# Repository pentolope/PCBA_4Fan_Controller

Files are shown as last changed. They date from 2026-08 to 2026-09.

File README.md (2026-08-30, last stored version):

# Four-Fan PWM/Tach Controller

Board that powers and controls four standard 4-wire 12 V PC fans, with a microcontroller giving independent PWM and tach per fan from a single 12 V input.

This repository holds the design problem for a four-channel PC fan controller. The brief fixes the function and almost nothing else: four standard 4-wire 12 V PC fans are powered and controlled from the board, a microcontroller generates independent PWM and reads independent tach signals, the board accepts a single 12 V input and derives its logic power locally, protection is required, and a simple host interface is to be provided. It also asks that the board be kept compact and serviceable, without stating any dimension, outline, or mounting scheme.

At brief detail 1/5, everything below that statement of function is left to the design agent: microcontroller family, logic rail voltage and regulator topology, host interface protocol and physical connection, how the fans and the 12 V input attach to the board, per-fan current budget, what "sensible protection" concretely covers, board outline, and stackup. Those choices belong in the design record as decisions with rationale, not as requirements attributed to the brief.

> **This board has not been designed.** There is no schematic, no layout and no
> part selection here — only the brief, a reading of the brief, and the
> scaffolding a design run needs. That is the intended state of this repository,
> not a gap in it.

## What the brief fixes, and what it leaves open

The brief pins down 11 requirements and deliberately leaves
17 decisions to whoever designs the board. The `Source` column says
which is which: `brief` is quoted from [BRIEF.md](BRIEF.md), `metadata` comes
from the benchmark catalogue, and `open` means the brief does not fix it.

| Aspect | Value | Source |
|---|---|---|
| Fan channels | Four standard 4-wire 12 V PC fans, powered and controlled by the board | brief |
| Fan control signals | Independent PWM per fan (four independent PWM outputs) | brief |
| Fan feedback signals | Independent tach read per fan (four independent tach inputs) | brief |
| Control element | A microcontroller performs PWM generation and tach reading; no family, package, or vendor named | brief |
| Power input | A single 12 V input, accepted by the board; the brief fixes one 12 V input and says nothing about whether anything else (for example the host link) also supplies power | brief |
| Logic power | Derived locally on the board rather than supplied externally; rail voltage and conversion method not stated | brief |
| Protection | Protection is required; the brief says only "sensible" and names no fault modes or devices | brief |
| Host interface | A simple host interface is to be provided; protocol, physical layer, and physical connection not specified | brief |
| Mechanical intent | Compact and serviceable; no dimensions, outline, mounting pattern, or enclosure stated | brief |
| Likely layer count | 2 | metadata |
| Category / difficulty / brief detail | mixed-power-digital; difficulty 2/5; detail 1/5 | metadata |
| Primary stressors | PWM/tach routing, 12V distribution, connector density, power thermal | metadata |
| Microcontroller, regulator, and connector selection | Not fixed by the brief — design agent's choice, to be justified in the design record | open |
| Board outline, stackup, and 12 V current budget | Not fixed by the brief — design agent's choice; no size, copper weight, or per-fan current is stated | open |
| Whether any supply other than the 12 V input exists | Not fixed by the brief — one 12 V input is fixed and logic power must be derived locally, but the brief does not say whether the host connection or a programming/bring-up link may also carry power; the design agent decides and records this | open |

The full split, with the verbatim brief text substantiating every fixed
requirement, is in [board/requirements.md](board/requirements.md) and
machine-readably in [board/requirements.json](board/requirements.json).

**Missing details are design freedom, not permission to fabricate unstated user
requirements.** A choice the brief left open is recorded as a decision, with its
reasoning — never promoted into a requirement.

## Benchmark position

| | |
|---|---|
| Benchmark id | 4 of 32 |
| Category | mixed-power-digital |
| Difficulty | 2 / 5 |
| Brief detail | 1 / 5 |
| Likely layer count | 2 |
| Primary stressors | PWM/tach routing, 12V distribution, connector density, power thermal |

This is a mixed-power-digital board at difficulty 2/5 with a detail 1/5 brief — a modest circuit whose difficulty lies in the interface between a 12 V power path and low-voltage digital control on a likely 2-layer stackup. The named stressors are PWM/tach routing, 12V distribution, connector density, and power thermal: four fan connections plus the 12 V input and the host interface all have to land on a board the brief asks to keep "compact", whatever connector scheme is chosen, while eight switching and feedback signals route alongside the fan current path. Because the brief specifies function but no parts, voltages, currents, or geometry, it primarily tests whether an agent can carry a thin brief forward with documented engineering decisions instead of back-filling invented user requirements.

This repository is one of thirty-two. The suite, the protocol and the results
live in [PCBA_AutoDesignAndTest_Bench](https://github.com/pentolope/PCBA_AutoDesignAndTest_Bench).

## Repository layout

| Path | Contents |
|---|---|
| `BRIEF.md` | the supplied brief — authoritative, preserved byte for byte, never edited |
| `board/requirements.md` | what the brief fixes, what it leaves open, and where decisions get recorded |
| `board/requirements.json` | the same split, machine-readable, each fixed requirement bound to brief text |
| `board/manifest.template.json` | the toolkit's minimum manifest, pre-filled for this board |
| `board/toolchain.json` | where this board's build finds KiCad and the router |
| `benchmark/metadata.json` | the supplied catalogue entry — category, difficulty, detail, stressors |
| `docs/architecture.md` | the decisions this board must make, as questions, unanswered |
| `docs/sources.md` | the classes of evidence the design will have to cite |
| `docs/status.md` | what exists, what does not, and what is deliberately absent |
| `candidates/` | disposable search output, ignored by Git |
| `.claude/skills/` | the accountability-review skill [CLAUDE.md](CLAUDE.md) requires before a push |
| `tooling/PCBA_AutoDesignAndTest` | the shared verification/routing/release toolkit, as a pinned submodule |

## Getting the repository

The toolkit is a submodule and carries KiCad Routing Tools as a submodule of its
own, so clone recursively:

```bash
git clone --recursive https://github.com/pentolope/PCBA_4Fan_Controller.git
```

```bash
git submodule update --init --recursive
```

## Designing the board

Generic verification, routing and release logic is **not** written here. It is
consumed from `tooling/PCBA_AutoDesignAndTest`, which is board-agnostic by
construction and must stay that way; this repository owns the board and nothing
else. Start from
[the toolkit's onboarding guide](tooling/PCBA_AutoDesignAndTest/examples/onboarding.md),
and see [CLAUDE.md](CLAUDE.md) for the rules a design run works under.

```bash
python3 tooling/PCBA_AutoDesignAndTest/run.py preflight
```

## Brief integrity

`BRIEF.md` SHA-256 `531862b585105d510d5cae2a7e9f812644b966f14cebd01fc22d28720cdb2ca3`

Every quotation in `board/requirements.json` is bound to those exact bytes. If
the brief ever changes, the bindings are stale by construction — which is the
point of recording the digest.

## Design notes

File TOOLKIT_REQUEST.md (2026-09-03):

# Toolkit requests from board 04 (QuadFanController)

What this board needed from `PCBA_AutoDesignAndTest` and did not get, what it
had to build for itself that every other board will have to build again, and
what it still cannot establish about its own reliability.

Written after taking the board to a release-ready state: 22 applicable gates
pass, 177 requirement claims stand at 176 PASS and 1 UNKNOWN, `release-check`
reports RELEASE READY. Everything below is therefore a request about the *next*
board as much as this one.

**Every request here is board-agnostic by construction.** Board 04 appears only
as evidence — what it measured, what it cost, what it could not answer. Nothing
asks the toolkit to learn anything about fans, four channels, or this netlist.
Where a board must supply something specific, the request says so and names the
declaration, not the value.

I surveyed `pcbqa/` before writing this. Section E lists what already exists and
must not be rebuilt; several things I expected to ask for are already there.

---

## A. Blockers hit while building this board

These cost real time on board 04 and will cost it again unchanged. They are
ordered by how much they cost.

### A1. The router grades the board against a floor it lowers itself

**Problem.** `KiCadRoutingTools` carries its own fab-capability floor —
`py_router/fab_tiers.py` gives a two-layer `standard` board 0.127 mm clearance
and 0.127 mm track width — and individual routing steps escalate *below* the
nominal `--clearance` to fit tight geometry. `py_router/clearance_ledger.py`
records the tightest value any step used, and its own docstring states where
that value goes: into `fix_project_for_output`, which rewrites the sibling
`.kicad_pro` DRC floor so the board is subsequently graded at the relaxed
value.

This board declares 0.15 mm and is graded at 0.15 mm. Every clearance violation
I chased for several routing cycles — 37 in one candidate, 42 in another, all
between 0.116 mm and 0.144 mm — was copper that is legal at 0.127 and illegal
at 0.15. Nothing in the flow said so. The router reported success; the summary
field `min_clearance_used: 0.127` was the only trace, and it is not surfaced by
any gate.

Passing `--fab-overrides` with the board's declared constraints fixed it
completely: the accepted candidate then reported `min_clearance_used: 0.3`, the
full nominal, and the violations disappeared at the source rather than being
patched afterwards.

**Request.** The toolkit's routing entry point should own this:

1. derive the router's fab-floor override file from the board's declared
   constraints (the same values `DRC.CONSTRAINT_FLOOR` already checks) and pass
   it on every invocation, so the router cannot emit copper the checker will
   reject;
2. read back the router's reported minimum clearance and **refuse the
   candidate** when it is below the board's declared clearance, naming both
   numbers;
3. detect that a router invocation rewrote the project's DRC floor and treat it
   as a finding, not as housekeeping. A tool lowering the threshold a later gate
   reads is check-weakening arriving through the back door, and the board author
   currently has to know it happens to defend against it.

**Done when** a board whose declared clearance is tighter than the router's tier
floor either routes at its declared clearance or fails with a message naming the
two floors — and no board-owned code has to know that `fab_tiers.py` exists.

### A2. The router is not deterministic, and the candidate search is board-owned

**Problem.** The same placed board, the same ordering, the same options,
re-run: 0 errors, then 44, then 64. Attempts 1 and 2 reproduced exactly while
attempt 3 did not, so this is not a seeded search the caller can pin.

That makes routing a search whose acceptance must be repeated, and every board
must therefore own: attempt loop, ordering list, per-attempt staging, the
acceptance predicate, retry-on-rejection, and the provenance record of what was
tried. `design/route.py` on this board is ~300 lines of exactly that, and
`routing_record.py` validates the record it produces but does not produce it.

**Request.** A toolkit-owned candidate search: the board declares the router
options, the orderings, the attempt budget and the acceptance predicate (as a
set of counters that must be zero — this board uses errors, warnings,
unconnected, schematic parity); the toolkit runs the attempts, stages each one,
applies the declared transforms, measures, promotes the first accepted candidate
into the authoritative board and emits the record `routing_record.validate`
already knows how to check. It should also report the accept rate across
attempts, because that number is the honest measure of how reproducible a
board's routing is.

**Done when** a board can obtain an accepted, recorded routing run without
owning a loop, and two runs of the same board report the same verdict even
though the router does not return the same copper.

### A3. Post-router geometry repair is board-owned and easy to get wrong

**Problem.** Router output is not directly acceptable. This board needed seven
transforms, all generic, none board-specific:

- snap a track end standing inside a same-net via's annulus onto its centre;
- pull a track end that stopped inside a same-net pad's outline onto the pad
  anchor (a 45° corner landing in the cut corner of a rounded rectangle reads as
  connected to KiCad's connectivity and as a bare end to everything else);
- drop tracks a snap collapsed to zero length;
- widen any track the router necked below the declared floor;
- restore the declared size on any via the router narrowed;
- absorb chamfer fragments a few tens of microns long into their single
  neighbour, away from pads and vias;
- prune dangling ends.

The last three are only safe under a connectivity-invariance guard: apply,
rebuild connectivity, and revert if the unconnected count rose. I wrote that
guard three times across two stages of this work.

**Request.** These transforms belong in the toolkit, each with the invariance
guard built in, each reporting what it changed so the routing record can carry
it. The board should declare which to apply and with what tolerances, not
implement them.

**Done when** a board gets router output into an acceptable state by declaring a
transform list, and the effects appear in the routing record without board-side
bookkeeping.

### A4. KiCad object identity has a trap that silently disables correct code

**Problem.** `str(track.m_Uuid)` returns a SWIG proxy repr — an address, reused
as objects are freed. On this board, **1190 tracks shared 3 distinct strings**.
Code comparing track identities that way is not merely wrong, it is wrong in the
direction that looks fine: my dangling-end prune skipped nothing, because every
track matched itself out of the neighbour scan and then held its own ends up.
The prune reported `dangling_tracks_removed: 0` for weeks of work while the
geometry gate kept reporting dangling ends, and the two facts never met.
`m_Uuid.AsString()` is the correct accessor.

**Request.** A `pcbqa` helper — `item_id(item)` — that returns the KIID string,
used by every toolkit path that compares board items, and one sentence in the
KiCad-interaction documentation stating the trap. This is three lines of code
that prevents a class of silent failure no test naturally catches, because the
broken version produces plausible output.

### A5. Saving a board rewrites the project document

**Problem.** `pcbnew.SaveBoard` rewrites the sibling `.kicad_pro` with KiCad's
own defaults, discarding the board's declared rule severities. On this board
that surfaced as `DRC.NO_SUPPRESSED_RULES` failing with five rules set to
"ignore" that the board never set to ignore. The fix — rewrite the project
document after every save — has to be remembered at every call site.

**Request.** A `pcbqa` save entry point that preserves the project document, and
which board-side layout code can use instead of `pcbnew.SaveBoard` directly.

### A6. Gate findings are not addressable

**Problem.** `ROUTE.GEOMETRY_HYGIENE` reports, for example,
`net=+3V3, layer=F.Cu, x_mm=71.8, y_mm=-42.9`. Those are KiCad-frame
coordinates with y negated, not board coordinates, and there is no item
identity. Locating each finding meant mapping the frame by hand and then
searching the board for copper near the point — several times per routing cycle,
and once with the wrong sign, which sent me looking at empty board area.

**Request.** Geometry findings should carry the board-frame coordinate *and* the
offending item's identity: net, layer, KIID, and where applicable the footprint
reference and pad number. `feedback.py` already establishes the principle — a
finding must name what failed, where, by how much, and which variables may move
— so this is asking the geometry gates to emit what that module already models.

**Done when** a finding can be resolved to the item it is about without a
coordinate-frame conversion in the reader's head.

### A7. Placement seeds need measured footprint geometry, not guesses

**Problem.** Seeding placement means knowing a footprint's courtyard extent and
where pad 1 sits after rotation. Both are empirical: rotation 90 puts pad 1
below the footprint centre and 270 above it; a vertical pin header places pad 1
at the origin and runs in −y. I discovered each by producing a board, running
DRC, reading the overlap, and adjusting — and eventually wrote a scratch script
to measure courtyard bounding boxes from the library so the constants could be
derived rather than guessed.

**Request.** A small geometry query on top of the footprint libraries:
courtyard extent, pad-1 position and pad centroid for a given footprint at a
given rotation. `geom.py` already reads pad outlines and mask openings from a
board; this is the same question asked of a library before a board exists.

### A8. `checks.<tool>.output` accepts a path that lands in the repository root

**Minor.** This board's manifest declared `"drc": {"output": "drc.json"}`; the
report landed at the repository root as an untracked file and nothing
complained. My fault, but the schema could refuse an output path that is not
inside a declared generated location.

---

## B. What the remaining stages need

Per `AUTONOMOUS_PCBA_AGENT.md`, this board has completed through §20 and §32.
§21–§26 are open. Some of what they need already exists; the gaps below are the
parts that do not.

### B1. A wired path from a board to the extraction modules that already exist

**Problem.** `extract.py`, `electrical_path.py`, `propagation.py`,
`coupling_geometry.py` and `stackup_physical.py` are present and do most of what
§21.1 asks. Board 04 uses none of them, and its `TIMING.*`, `STACK.PHYSICAL` and
`PROV.TIMING_MODELS` gates all report NOT_APPLICABLE because the manifest
declares no `timing` section. The capability exists; the route from a board to
it does not, and nothing tells a board author it is there.

**Request.** A documented opt-in: what a board declares to get Tier-1
extraction, what physical inputs it must supply as parameter records, and which
gates become applicable when it does. A worked minimal example in the toolkit's
own fixtures is worth more than prose.

**Done when** a board can obtain per-net conductor length, cross-section, DC
resistance, via inventory and reference-plane context as claims by declaring
inputs, without reading module source to discover the calling convention.

### B2. Pre-layout versus post-layout comparison (§22)

**Problem.** `simulation.required_stages` on this board is `["pre_layout"]`.
The scenario contract supports `model_instance`, and `extract.py` already offers
`interconnect_model_from_path` — a two-terminal model from a traced path — so
the primitives for substitution exist. What does not exist is the comparison the
doc actually asks for: *pre-layout model vs post-layout model*, stating which
quantity moved and by how much.

**Request.** A stage-comparison artifact and gate: given the same scenario run
in two stages, report per measurement the pre value, the post value, the change,
and whether the assertion's margin narrowed. A post-layout stage that merely
passes tells the reader nothing about what layout cost.

**Done when** a board can answer "did the routed copper change this margin, and
by how much" from an artifact rather than by diffing two reports by eye.

### B3. DC power integrity (§23) — absent

**Problem.** No module in `pcbqa` addresses IR drop, source-to-load DC
resistance over routed copper, current bottlenecks or plane spreading
resistance; a grep for the concepts returns nothing. Board 04 declares
`INPUT_PATH_BUDGET_OHM = 0.2` and `BOARD_COPPER_BUDGET_OHM = 0.03` as *budgets*
and has no way to measure what its routed rail and return actually are. It
carries 4 A through one input path and cannot state the drop.

`extract.py:path_resistance` gets close — DC resistance over an actual traversal
between two pads — but it refuses when the net carries filled zone copper, which
is precisely the case for a poured power rail and a ground return, so it does
not answer the power question.

**Request.** A DC distribution analysis: given a source pad, a set of load pads
and their currents, report the resistance and voltage drop along each path
**including plane and pour copper**, identify the narrowest point and the vias
carrying the most current, and emit claims with the model and its omissions
stated. Zone copper is the hard part and the reason this cannot be assembled
from what exists.

**Done when** a board that declares a rail's source, loads and currents receives
a measured drop it can compare against a declared budget, and a via or neck that
carries more current than the rest is named.

### B4. Thermal estimation (§24) — absent

**Problem.** No thermal capability exists. Two of this board's claims sit
exactly on the failure mode the agent doc names by hand — a junction temperature
from a generic package number whose boundary conditions do not match:

- `blocking_device_dissipation_within_its_rating` (Q1), omitting *"the package's
  power rating is quoted on the datasheet's own test board; the copper this
  board gives the drain is a layout quantity and is not yet measured"*;
- `regulator_junction_within_its_rating` (U2), omitting the same for its tab.

The copper now exists. The omissions can be closed, and cannot be closed by
anything in the toolkit.

**Request.** A copper-aware thermal estimate: pad and plane copper area attached
to a part, thermal via conductance, declared ambient and airflow as explicit
inputs, and a result **labelled an estimate** with its validity envelope stated.
It should refuse to emit a junction-temperature claim when the declared boundary
conditions fall outside the validity of the θJA it was given, rather than
quietly extrapolating — the doc asks for that refusal specifically.

**Done when** a dissipating part's claim can cite measured attached copper
instead of omitting it, and a board whose conditions do not match its
datasheet's test board is told so.

### B5. Design-for-assembly checks (§25) — absent

**Problem.** `gates/g_assembly.py` is BOM and CPL *parity* — it proves the
schematic, board and packaged files agree on what gets soldered. It is not DFA.
Nothing checks component height, insertion or mating access, side-of-board
population, paste segmentation on a thermal tab, hand-solder sets, moisture
sensitivity, or fiducials.

Board 04 is a case where access is a real constraint and is currently unchecked:
four fan headers and a screw terminal sit on the board edge, and nothing
verifies a plug can be inserted, or that a mating connector's body does not
collide with a neighbouring part.

**Request.** Assembly constraints as board-declared, toolkit-checked geometry:
height limits per region, keep-clear volumes for connector insertion and mating,
population side, and paste-mask rules. The connector contracts this board
already declares are the natural place to attach a mating envelope.

### B6. External and manual release dependencies (§25, §32)

**Problem.** Some release conditions cannot be established locally — the doc
names JLCPCB's assembly preview. Today they are either silently assumed or
recorded as prose that no gate reads.

**Request.** A manifest-declared external dependency with an acknowledgement
artifact: what must be checked outside the toolkit, by whom, and a recorded
result with a digest, so `release-check` blocks until an unacknowledged
dependency is either satisfied or explicitly declined. Recording it as an
open dependency is honest; assuming it silently is not.

### B7. Verification-method classification (§26)

**Problem.** Claims carry `evidence_class` (this board: 101
`datasheet-behavioral`, 66 `design-source`, 10 `assumed-behavioral`) and
`phenomenon` (all 177 `device_electrical`), but not the strongest verification
method available for the requirement. The doc's enumeration — STATIC, GEOMETRY,
ANALYTIC, CIRCUIT_SIM, DIGITAL_SIM, EXTRACTED, EM_SIM, THERMAL_SIM,
MANUFACTURING_CHECK, PHYSICAL_TEST, DOCUMENTATION — has no representation in
`claim.py`.

The consequence is that this board cannot say the true thing about several
requirements. Connector mating, TVS survival to a real ESD event, and the fan's
own rotor-lock behaviour are `PHYSICAL_TEST` and nothing else. Today the mating
requirement is the board's single UNKNOWN, which reads like an oversight rather
than like a correct statement that a bench test is required.

**Request.** A method field on claims, a gate that every significant requirement
names its strongest available method, and — the part that matters — a verdict
shape for "physical validation required" that is neither a FAIL nor an UNKNOWN
that looks like a gap. The doc says the agent should be rewarded for saying it;
right now there is nowhere to say it.

### B8. Board-contract export for firmware (§6.3)

**Problem.** This design determines firmware behaviour and records it only as
prose in comments: the PWM drivers are external open-drain N-FETs, so the
timer's channel polarity must be inverted; the 25 kHz target comes out as
ARR = 639 on a 16 MHz HSI; and the control gate sits at 2.664 V under the MCU's
internal pull-up before firmware runs, which constrains what the pin may be
configured to at boot. Firmware that gets any of these wrong runs the fans
backwards or full-speed. The doc's rule is not to maintain two independently
edited copies of the board contract, and today there is only prose to copy from.

**Request.** Generated machine-readable board contract: pin assignments,
voltage domains, clock sources, per-pin polarity and boot-state constraints,
derived from the netlist the board already declares. Format is the toolkit's
call; the requirement is that it is generated, not authored twice.

---

## C. Verifying this board's reliability

Three things I want and cannot get, all generic.

### C1. Flow repeatability

Given A2, "this board routes clean" is a statement about one run. The honest
claim is about the distribution: run generate → route → validate N times from
the same sources and report whether the verdict is stable and which gates ever
differ. That number belongs in the release evidence for any board whose routing
came from a non-deterministic search — which, today, is all of them.

### C2. Omission-closure report

Every claim states what it omits. Some omissions name quantities that were
unmeasurable at the stage the claim was written and are measurable now: on this
board, 8 of 177 claims omit a layout or thermal quantity that the routed board
now contains. I found that with an ad-hoc script to answer a question about what
work remained.

**Request.** A report listing every claim whose omissions name a quantity the
current stage can measure. It is the work list for post-layout verification,
it is derivable from the claim records the toolkit already owns, and it turns
"what is left to do" from a judgement call into a query.

### C3. Per-gate negative coverage

`tests/fixtures/negative/` holds one fixture, which drives 15 of the 36 gates to
FAIL. The other 21 have no fixture proving they fail when they should. A gate
that cannot be shown to bite is indistinguishable from a gate that always
passes, and the discipline this toolkit applies to boards — unknown is not pass
— applies to the checker too.

**Request.** Per-gate negative coverage, ideally by programmatic mutation of a
clean fixture: shrink a via below the annulus target, add a dangling track,
widen a fragment, break schematic parity, relax a project rule, and assert that
exactly the corresponding gate fails. Mutation is preferable to hand-built
fixtures because it stays honest as gates change.

---

## D. Constraints these requests must respect

Stated so no request above is read as licence to relax any of them:

- **Genericity.** Nothing in `pcbqa/` may know a board name. Every request above
  is phrased as a board declaration plus a toolkit behaviour.
- **Fail-closed.** A capability that cannot be evaluated reports ERROR and
  blocks. An extraction that cannot establish its inputs must refuse, not
  approximate silently.
- **Never weaken a check.** A1 is a request to *enforce* this at the router
  boundary, where a third-party tool currently lowers a threshold the toolkit
  later reads.
- **No live network in a verdict.** Anything acquired from outside is frozen
  with a digest first; B6 asks for a recorded acknowledgement, not a live query.
- **Never modify the authoritative board in place.** The candidate search in A2
  promotes a candidate; it does not edit the board being searched from.
- **Models carry provenance, applicability and omissions.** B3 and B4 in
  particular must state their model and what it leaves out — they are the two
  most tempting places to emit a bare number.

---

## E. Already present — do not rebuild

Surveyed before writing this, and deliberately not requested:

| Module | Covers |
| --- | --- |
| `extract.py` | Tier-1 geometry parasitics, parameter records with provenance, path resistance, two-terminal interconnect models |
| `electrical_path.py` | ElectricalPath across nets and through series parts, path resolution against copper |
| `propagation.py` | Analytic delay from geometry and physical stackup, with evidence ranking and via policy |
| `coupling_geometry.py` | Measured parallel-run inventory (geometry, explicitly not a crosstalk voltage) |
| `stackup_physical.py` | Physical vs structural stackup, reference geometry |
| `critical_topology.py` | Deterministic local copper at declared fabrication values |
| `placement.py`, `feedback.py` | Semantic placement constraints; structured downstream-to-placement feedback records |
| `routing_record.py` | Validation of the routing record and its agreement with the adopted board |
| `connectivity.py`, `geom.py` | Copper connectivity by geometric intersection; native pad/mask/via geometry |
| `sim/` | Scenario contract, ngspice backend, model registry, digital |
| `fabricators/` | JLCPCB catalogue, acquisition, selection, impedance, stackup export |
| `claim.py`, `closure.py` | Evidence and numeric-claim contracts; source closure identity |

The pattern across A and B is that the toolkit's *analysis* layer is strong and
its *board-facing* layer is thin: the capabilities exist but each board hand-
rolls the path to them, and the two places where a board meets an external tool
— the router, and anything outside the repository — are where it silently
inherits someone else's standards instead of its own.

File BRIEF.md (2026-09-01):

# PCBA_4Fan_Controller — Four-Fan PWM/Tach Controller
## Design brief

Build a board that powers and controls four standard 4-wire 12 V PC fans. A microcontroller should generate independent PWM and read independent tach signals. Accept a single 12 V input, derive logic power locally, include sensible protection, and provide a simple host interface. Keep it compact and serviceable.

## Functional requirements

- Four channels driven and measured independently; a stalled, shorted or unplugged fan must not disturb the others.
- Duty must cover the range the 4-wire control interface defines, identically on every channel.
- Tach must read as a rate convertible to RPM; an absent or stalled fan must be distinguishable from one commanded off.

## Fan channel interface

- PWM outputs must run inside the band the 4-wire fan standard allows, sink its control-input current at a valid low, and tolerate the fan's pull-up with the logic rail unpowered.
- Tach inputs must supply their own pull-up, present a load the fan can pull low, and pass every pulse at top speed.

## Power and protection

- 12 V in is the only external supply; the logic rail comes from it on board and holds through fan inrush.
- Per-channel current must be stated, connectors and copper must carry all four at once, and fan return must not share the tach reference.
- Reverse polarity, a fan pin shorted to 12 V or ground, back-EMF, overcurrent on one channel, host hot-plug and handling ESD must leave the board and the other channels working; recovery must be documented.

## Connectors, service and test

- One connector per fan, mating a standard 4-wire PC fan plug in the standard pin order, keyed and labelled per channel.
- The host interface is one connector, needs no host power, and at least sets duty and reports tach and fault state per channel.
- Any fan must be unpluggable by hand while the others run; outline no larger than connectors and power path require.
- In-system reprogramming and test points on protected 12 V, the logic rail, ground and every PWM and tach net, board installed.

## Open choices

- MCU family and package: four independent PWM outputs at the fan drive frequency and resolution needed, four independent tach captures, the host peripheral, in-system programming.
- Logic rail voltage and regulator topology; host interface type and connector; whether fan 12 V is permanent or switched per channel; whether channel current is sensed; overcurrent shared or per channel, self-recovering or replaceable.

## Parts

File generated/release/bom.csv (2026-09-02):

Quantity | Designator | Comment | Footprint | LCSC Part #
2 | C1,C3 | 100uF | Capacitor_SMD:CP_Elec_6.3x7.7 | C2836443
5 | C2,C4,C6,C7,C8 | 100nF | Capacitor_SMD:C_0603_1608Metric | C14663
1 | C5 | 10uF | Capacitor_SMD:C_0805_2012Metric | C15850
4 | C9,C10,C11,C12 | 1nF | Capacitor_SMD:C_0603_1608Metric | C100040
1 | D1 | SMAJ16A | Diode_SMD:D_SMA | C74561
9 | D2,D3,D4,D5,D6,D7,D8,D9,D10 | B5819W | Diode_SMD:D_SOD-123 | C8598
8 | D11,D12,D13,D14,D15,D16,D17,D18 | SMF16A | QuadFanController:D_SOD-123FL_1.2x1.2mm_P3.2mm | C353308
5 | D19,D20,D21,D22,D23 | TPD1E10B06DPYR | QuadFanController:TI_X1SON-2_1.0x0.6mm_P0.65mm | C48260
1 | D24 | KT-0603R | LED_SMD:LED_0603_1608Metric | C2286
4 | F1,F2,F3,F4 | JK-MSMD200-24V | QuadFanController:PTC_1812_Jinrui_JK-mSMD | C561584
1 | J1 | KF128-5.08-2P-AA | QuadFanController:TerminalBlock_KF128-5.08_1x02_P5.08mm | C474952
4 | J2,J3,J4,J5 | KF2510-4AGW-GW | QuadFanController:FanHeader_2510_1x04_P2.54mm_Horizontal | C722747
1 | J6 | KH-2.54PH180-1X3P-L11.5 | Connector_PinHeader_2.54mm:PinHeader_1x03_P2.54mm_Vertical | C2932698
1 | J7 | KH-2.54PH180-1X5P-L11.5 | Connector_PinHeader_2.54mm:PinHeader_1x05_P2.54mm_Vertical | C2932699
1 | Q1 | AO4407A | Package_SO:SOIC-8_3.9x4.9mm_P1.27mm | C16072
4 | Q2,Q3,Q4,Q5 | AO3401A | Package_TO_SOT_SMD:SOT-23 | C15127
8 | Q6,Q7,Q8,Q9,Q10,Q11,Q12,Q13 | AO3400A | Package_TO_SOT_SMD:SOT-23 | C20917
17 | R1,R2,R3,R4,R5,R6,R7,R8,R9,R10,R11,R12,R13,R18,R19,R20,R21 | 100k | Resistor_SMD:R_0603_1608Metric | C25803
4 | R14,R15,R16,R17 | 100R | Resistor_SMD:R_0603_1608Metric | C22775
4 | R22,R23,R24,R25 | 47R | Resistor_SMD:R_0603_1608Metric | C23182
8 | R26,R27,R28,R29,R30,R31,R32,R33 | 4.7k | Resistor_SMD:R_0603_1608Metric | C23162
5 | R34,R35,R36,R37,R42 | 33k | Resistor_SMD:R_0603_1608Metric | C4216
5 | R38,R39,R40,R41,R43 | 10k | Resistor_SMD:R_0603_1608Metric | C25804
1 | R44 | 1.5k | Resistor_SMD:R_0603_1608Metric | C22843
1 | R45 | 0R | Resistor_SMD:R_0603_1608Metric | C21189
2 | R46,R47 | 2.2k | Resistor_SMD:R_0603_1608Metric | C4190
2 | R48,R49 | 470R | Resistor_SMD:R_0603_1608Metric | C23179
1 | U1 | STM32G030K8T6 | Package_QFP:LQFP-32_7x7mm_P0.8mm | C724044
1 | U2 | HT75R33-1A | Package_TO_SOT_SMD:SOT-89-3 | C53223865

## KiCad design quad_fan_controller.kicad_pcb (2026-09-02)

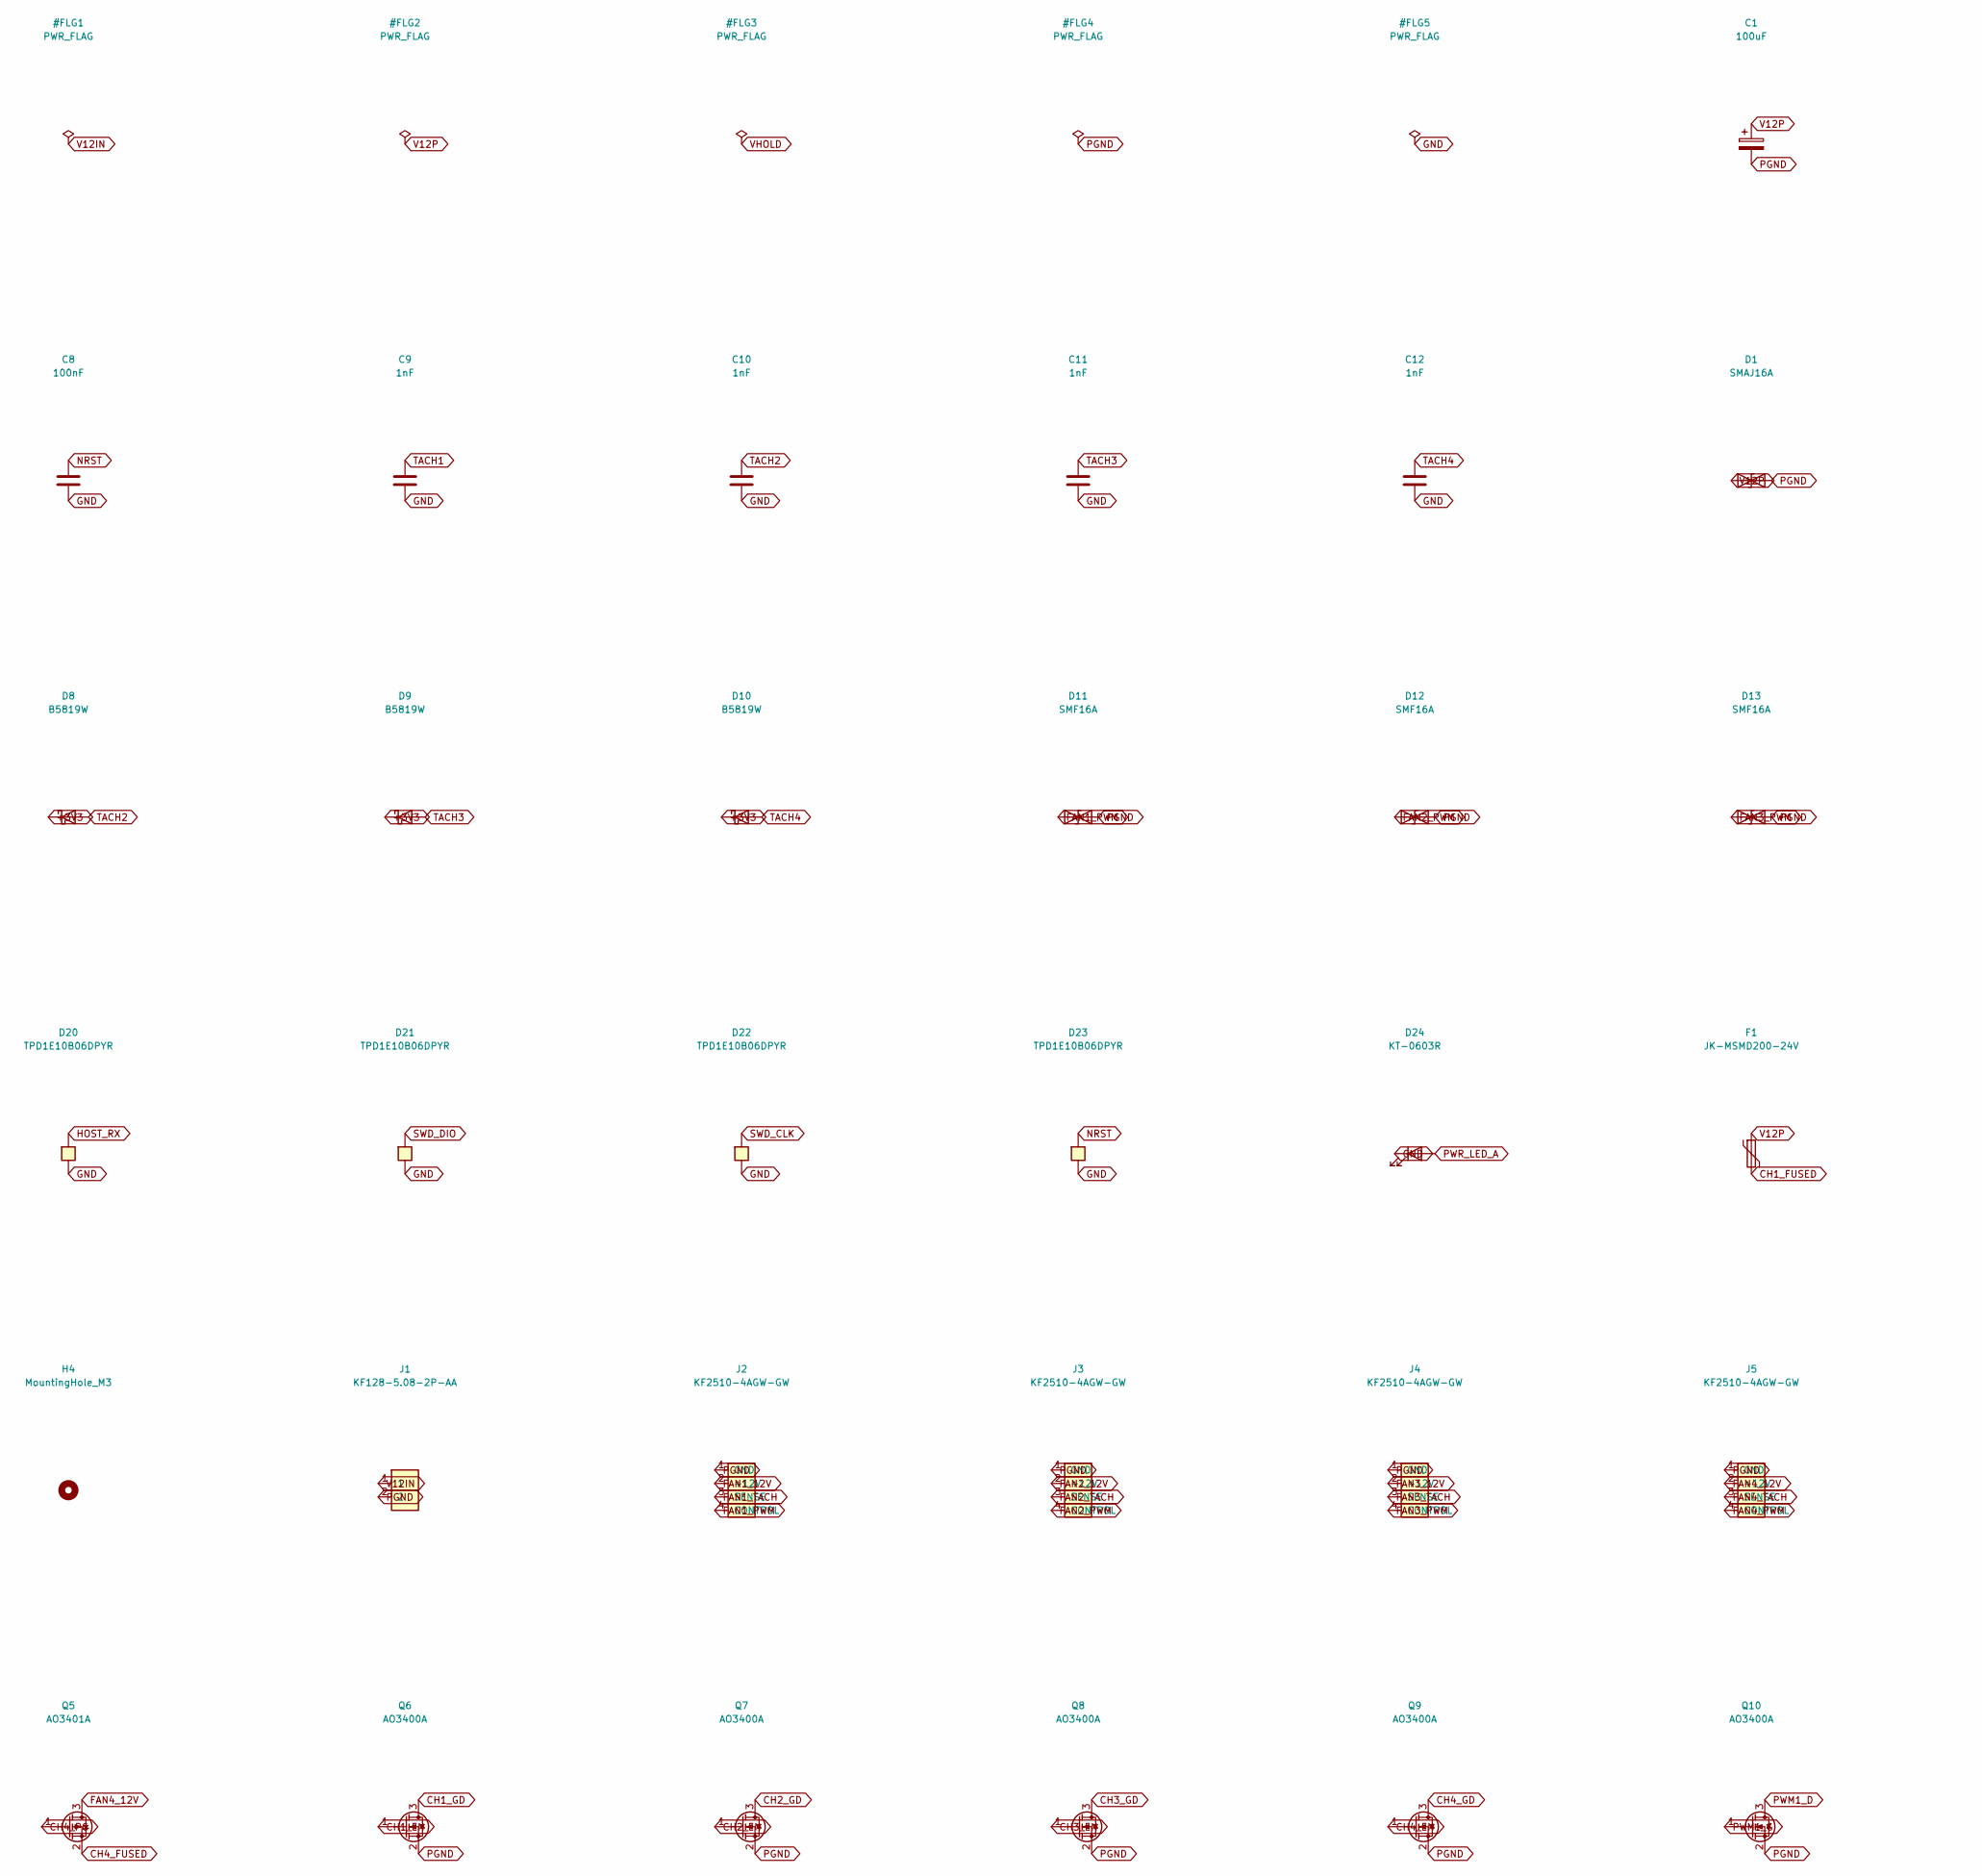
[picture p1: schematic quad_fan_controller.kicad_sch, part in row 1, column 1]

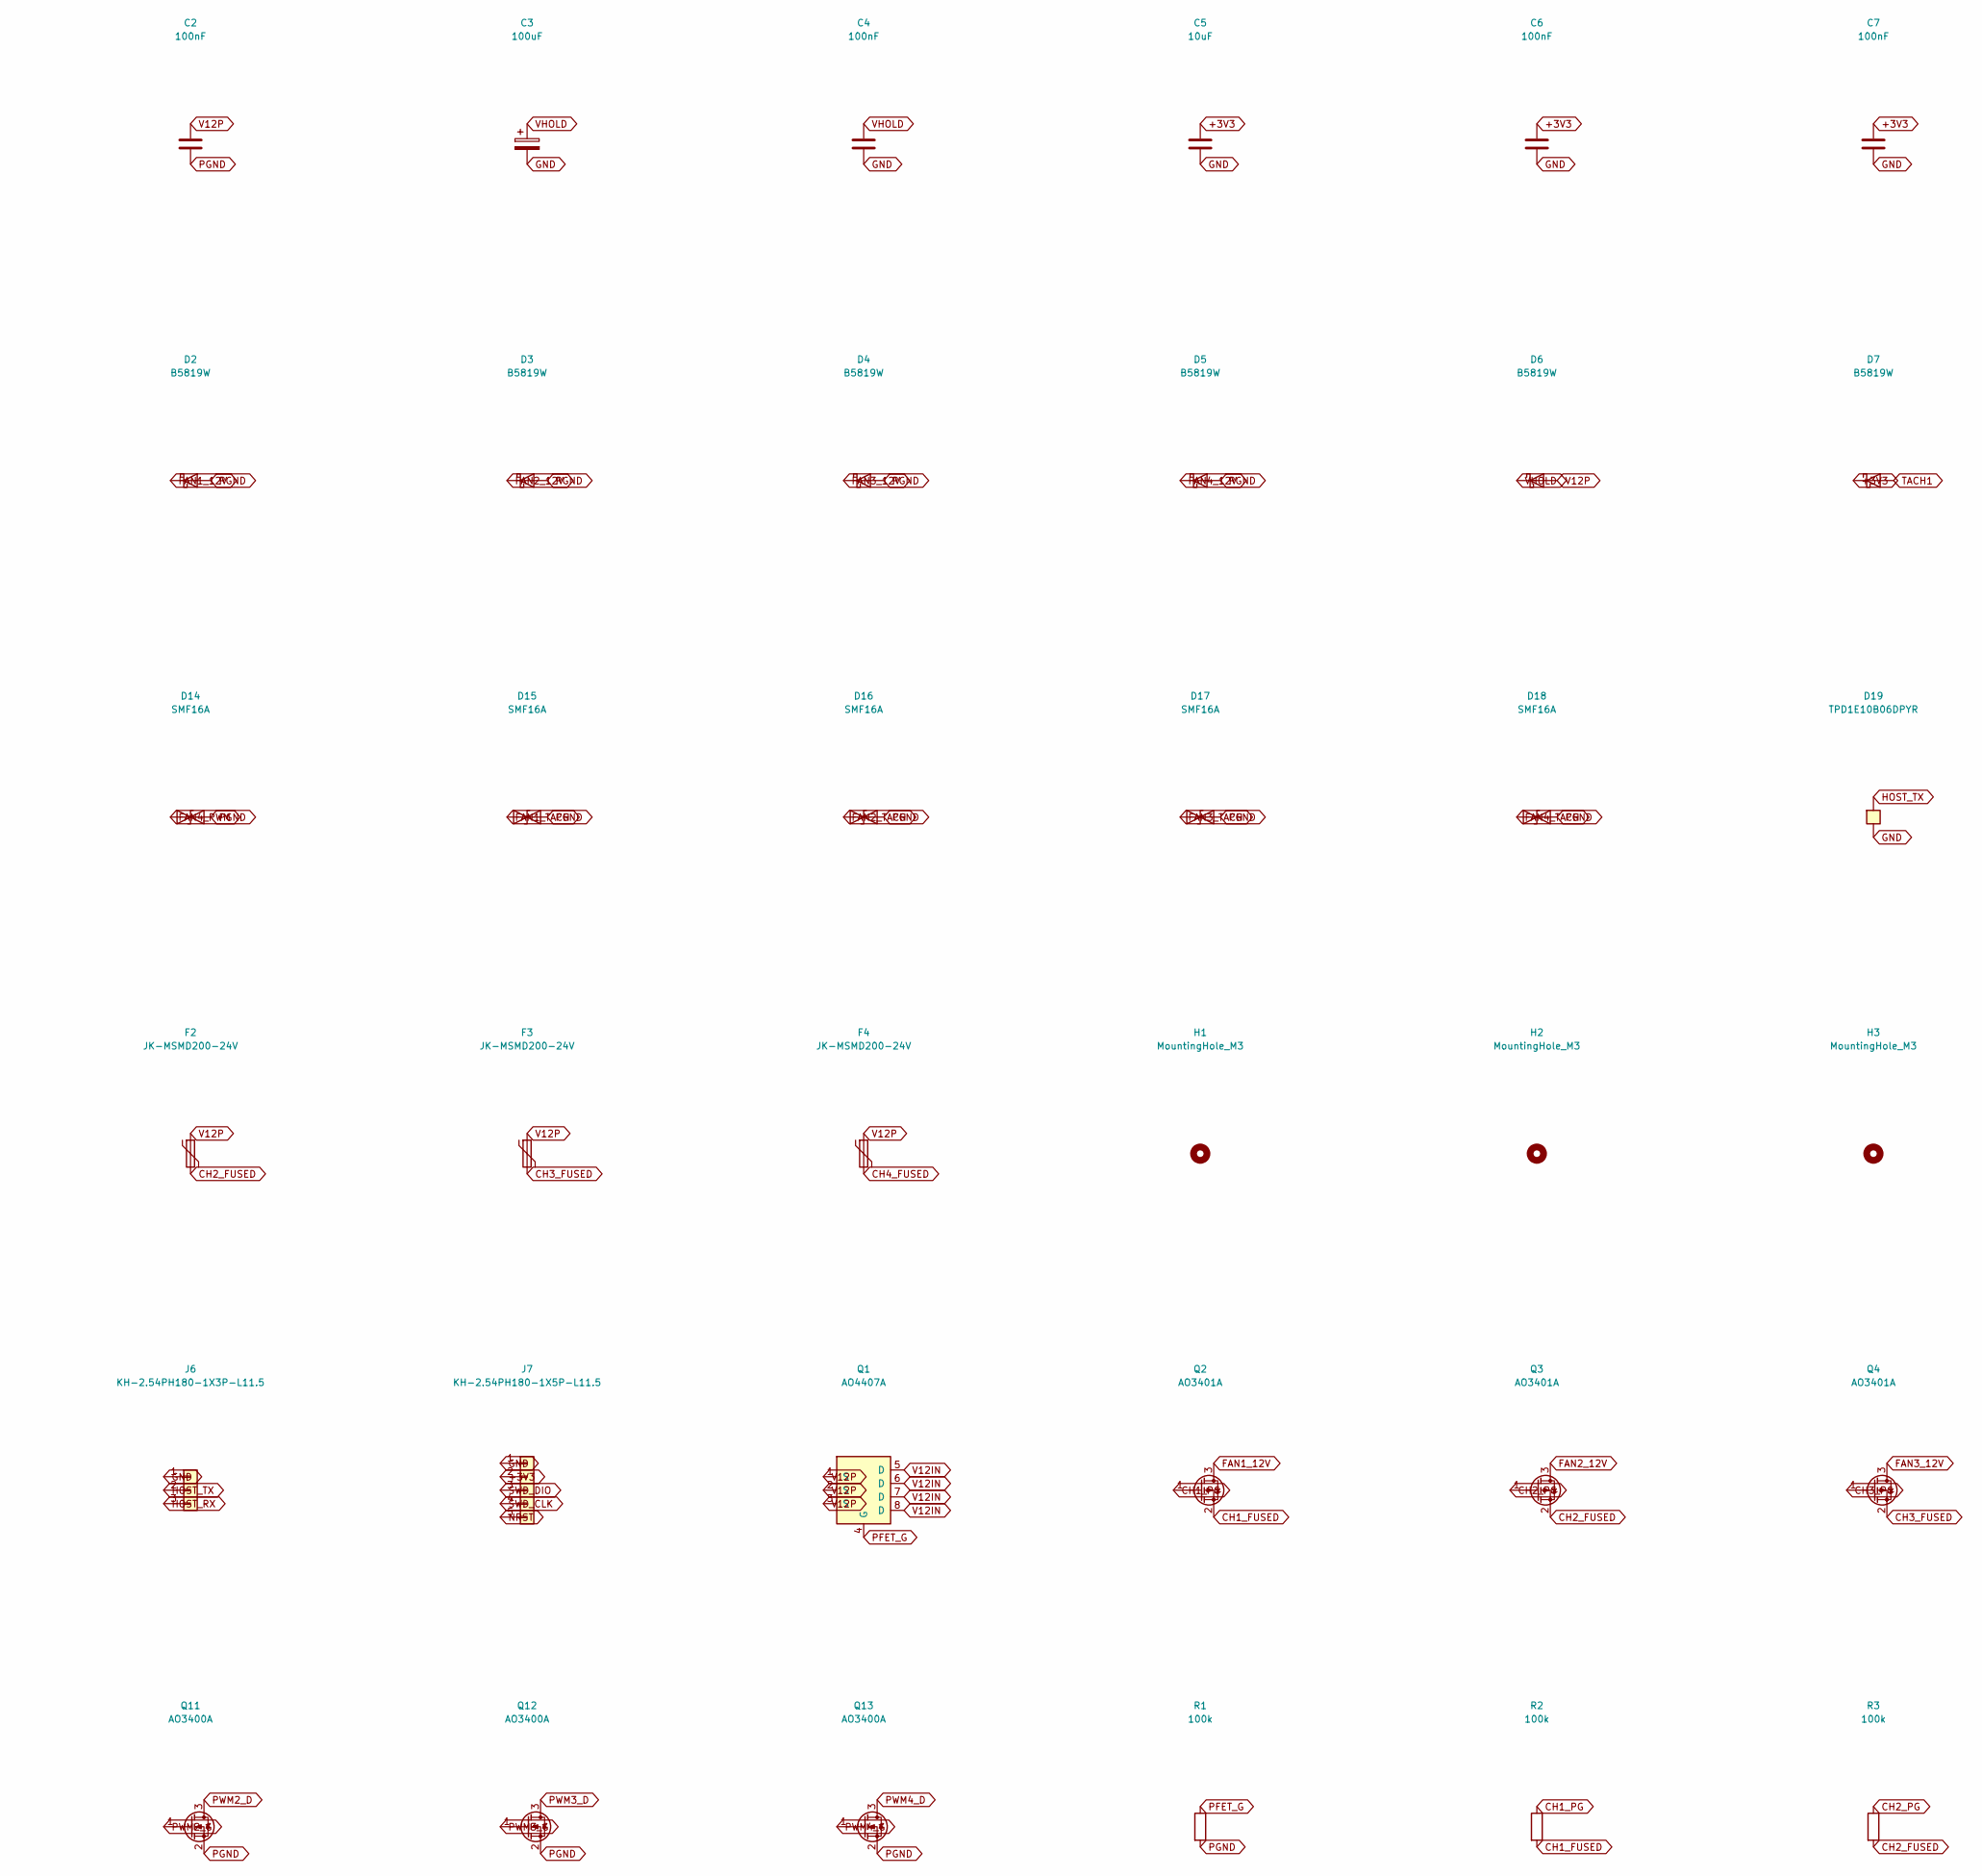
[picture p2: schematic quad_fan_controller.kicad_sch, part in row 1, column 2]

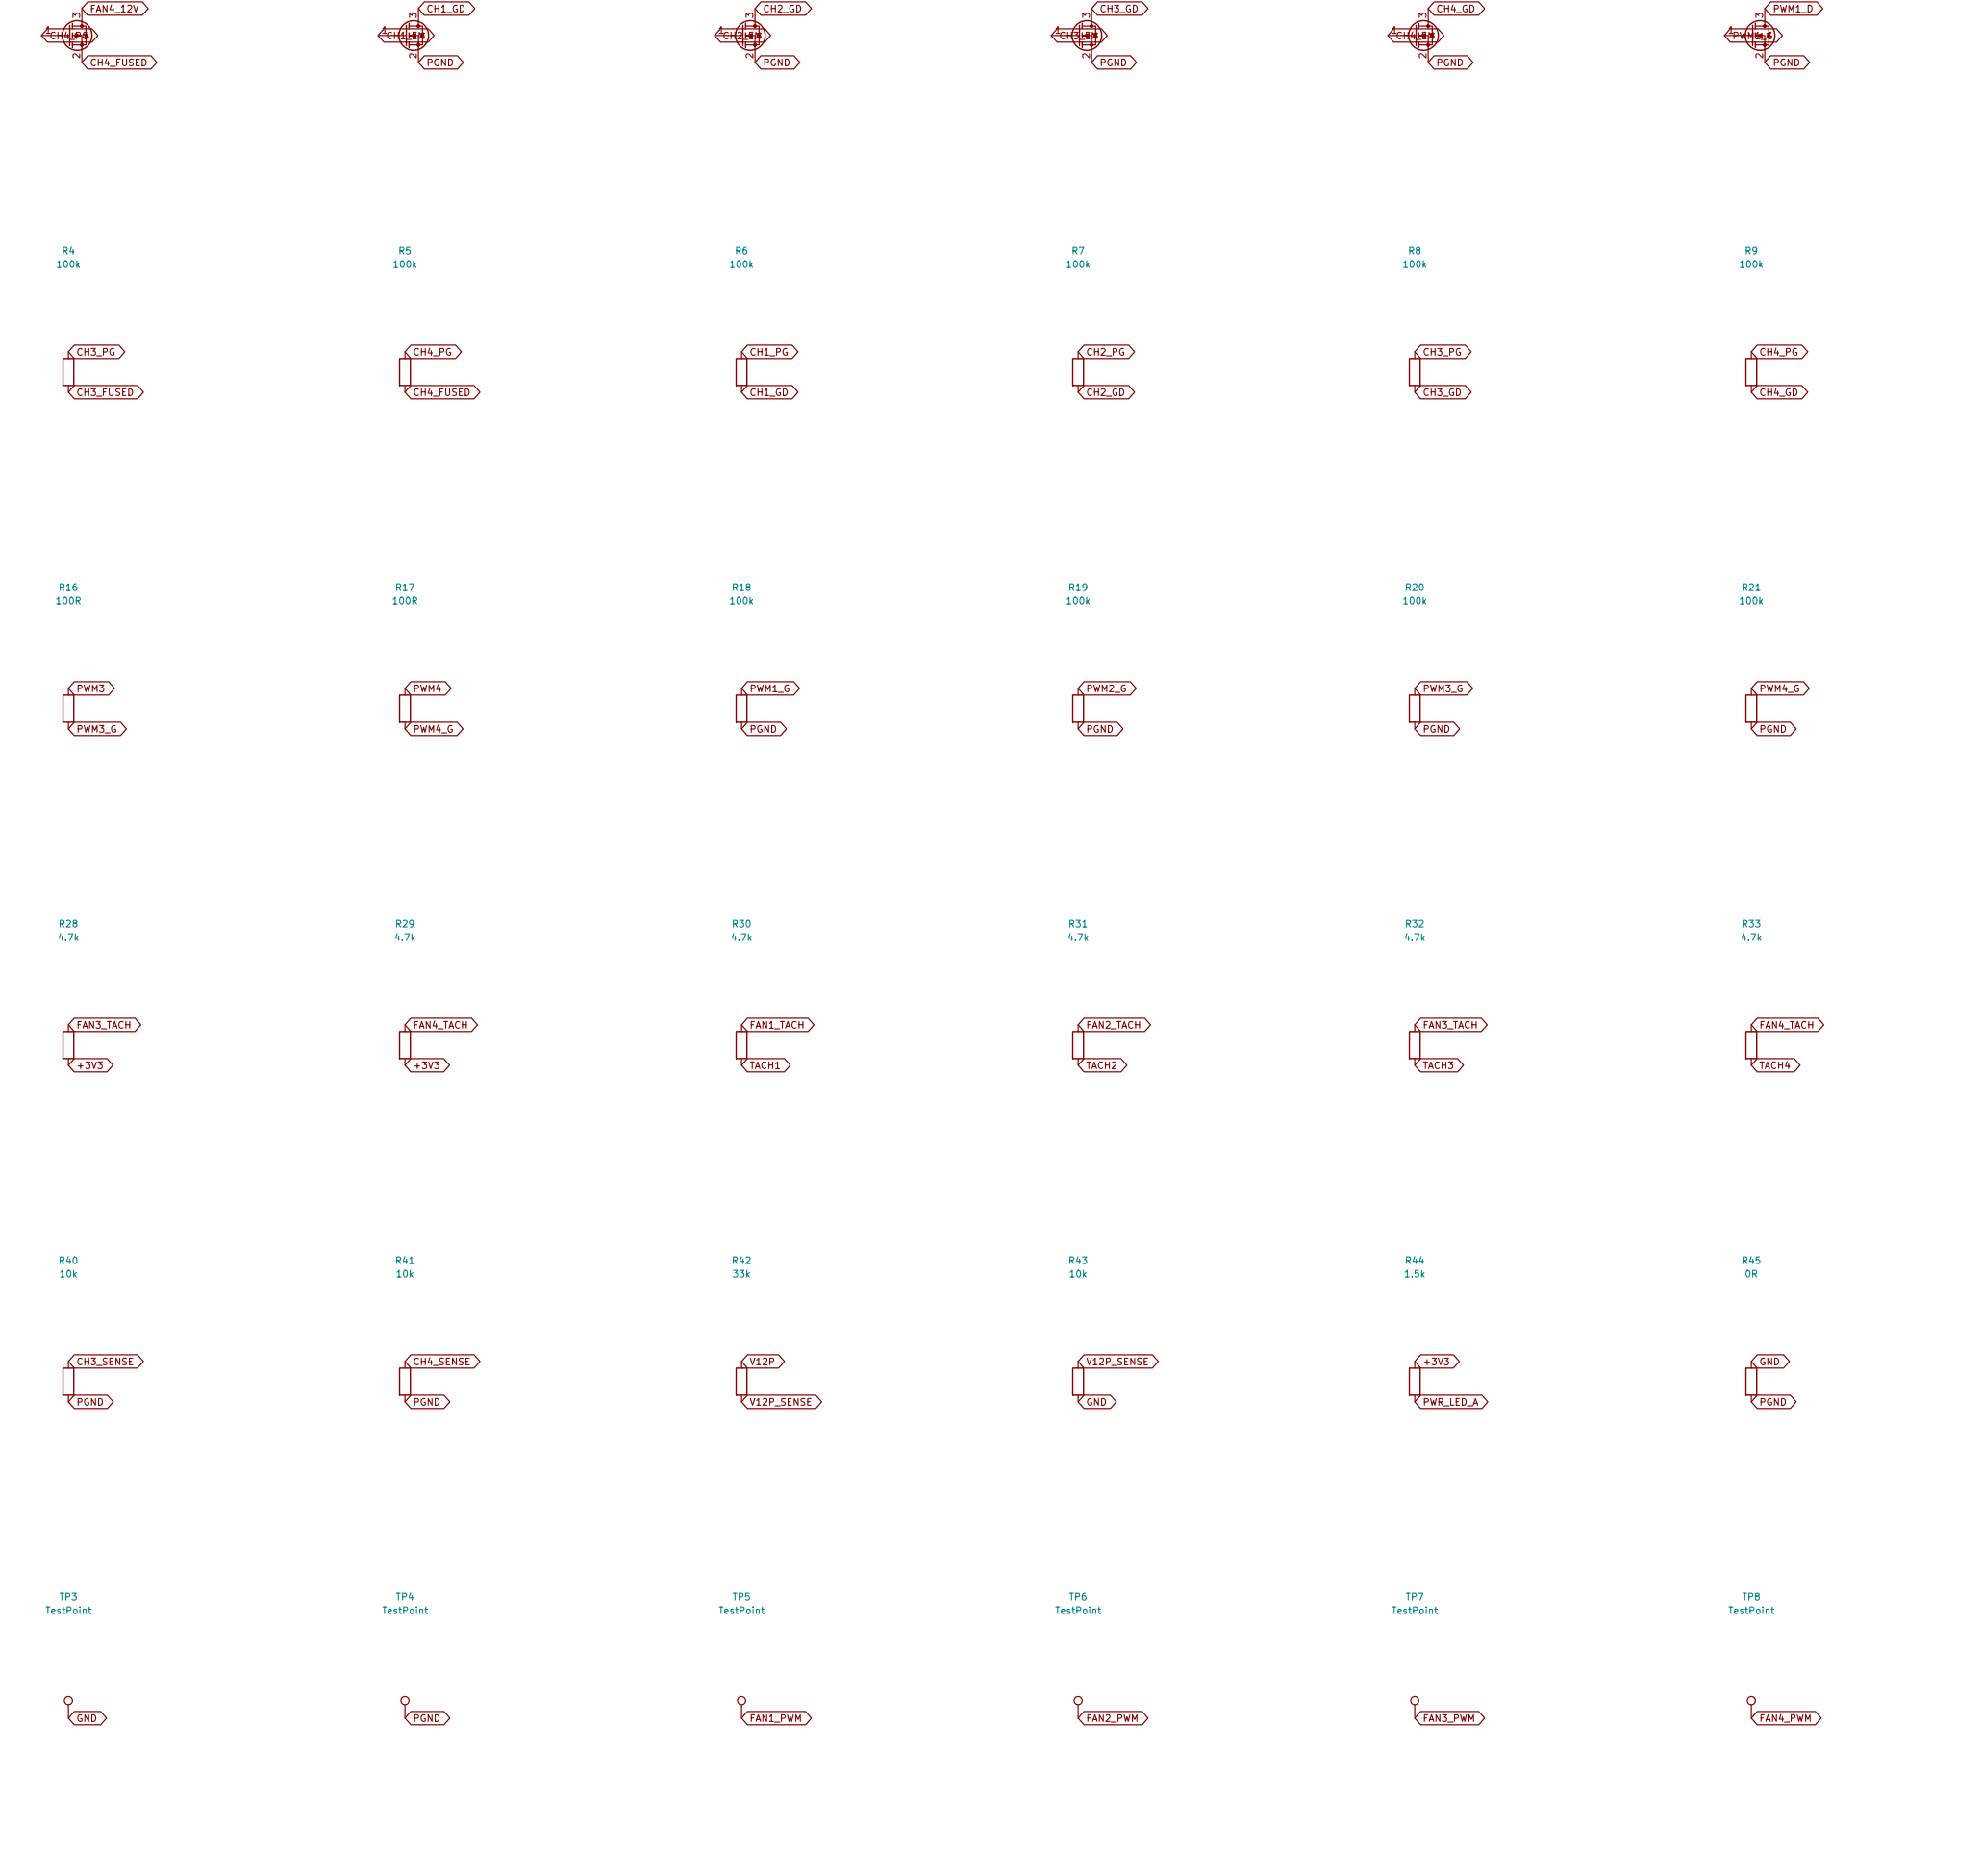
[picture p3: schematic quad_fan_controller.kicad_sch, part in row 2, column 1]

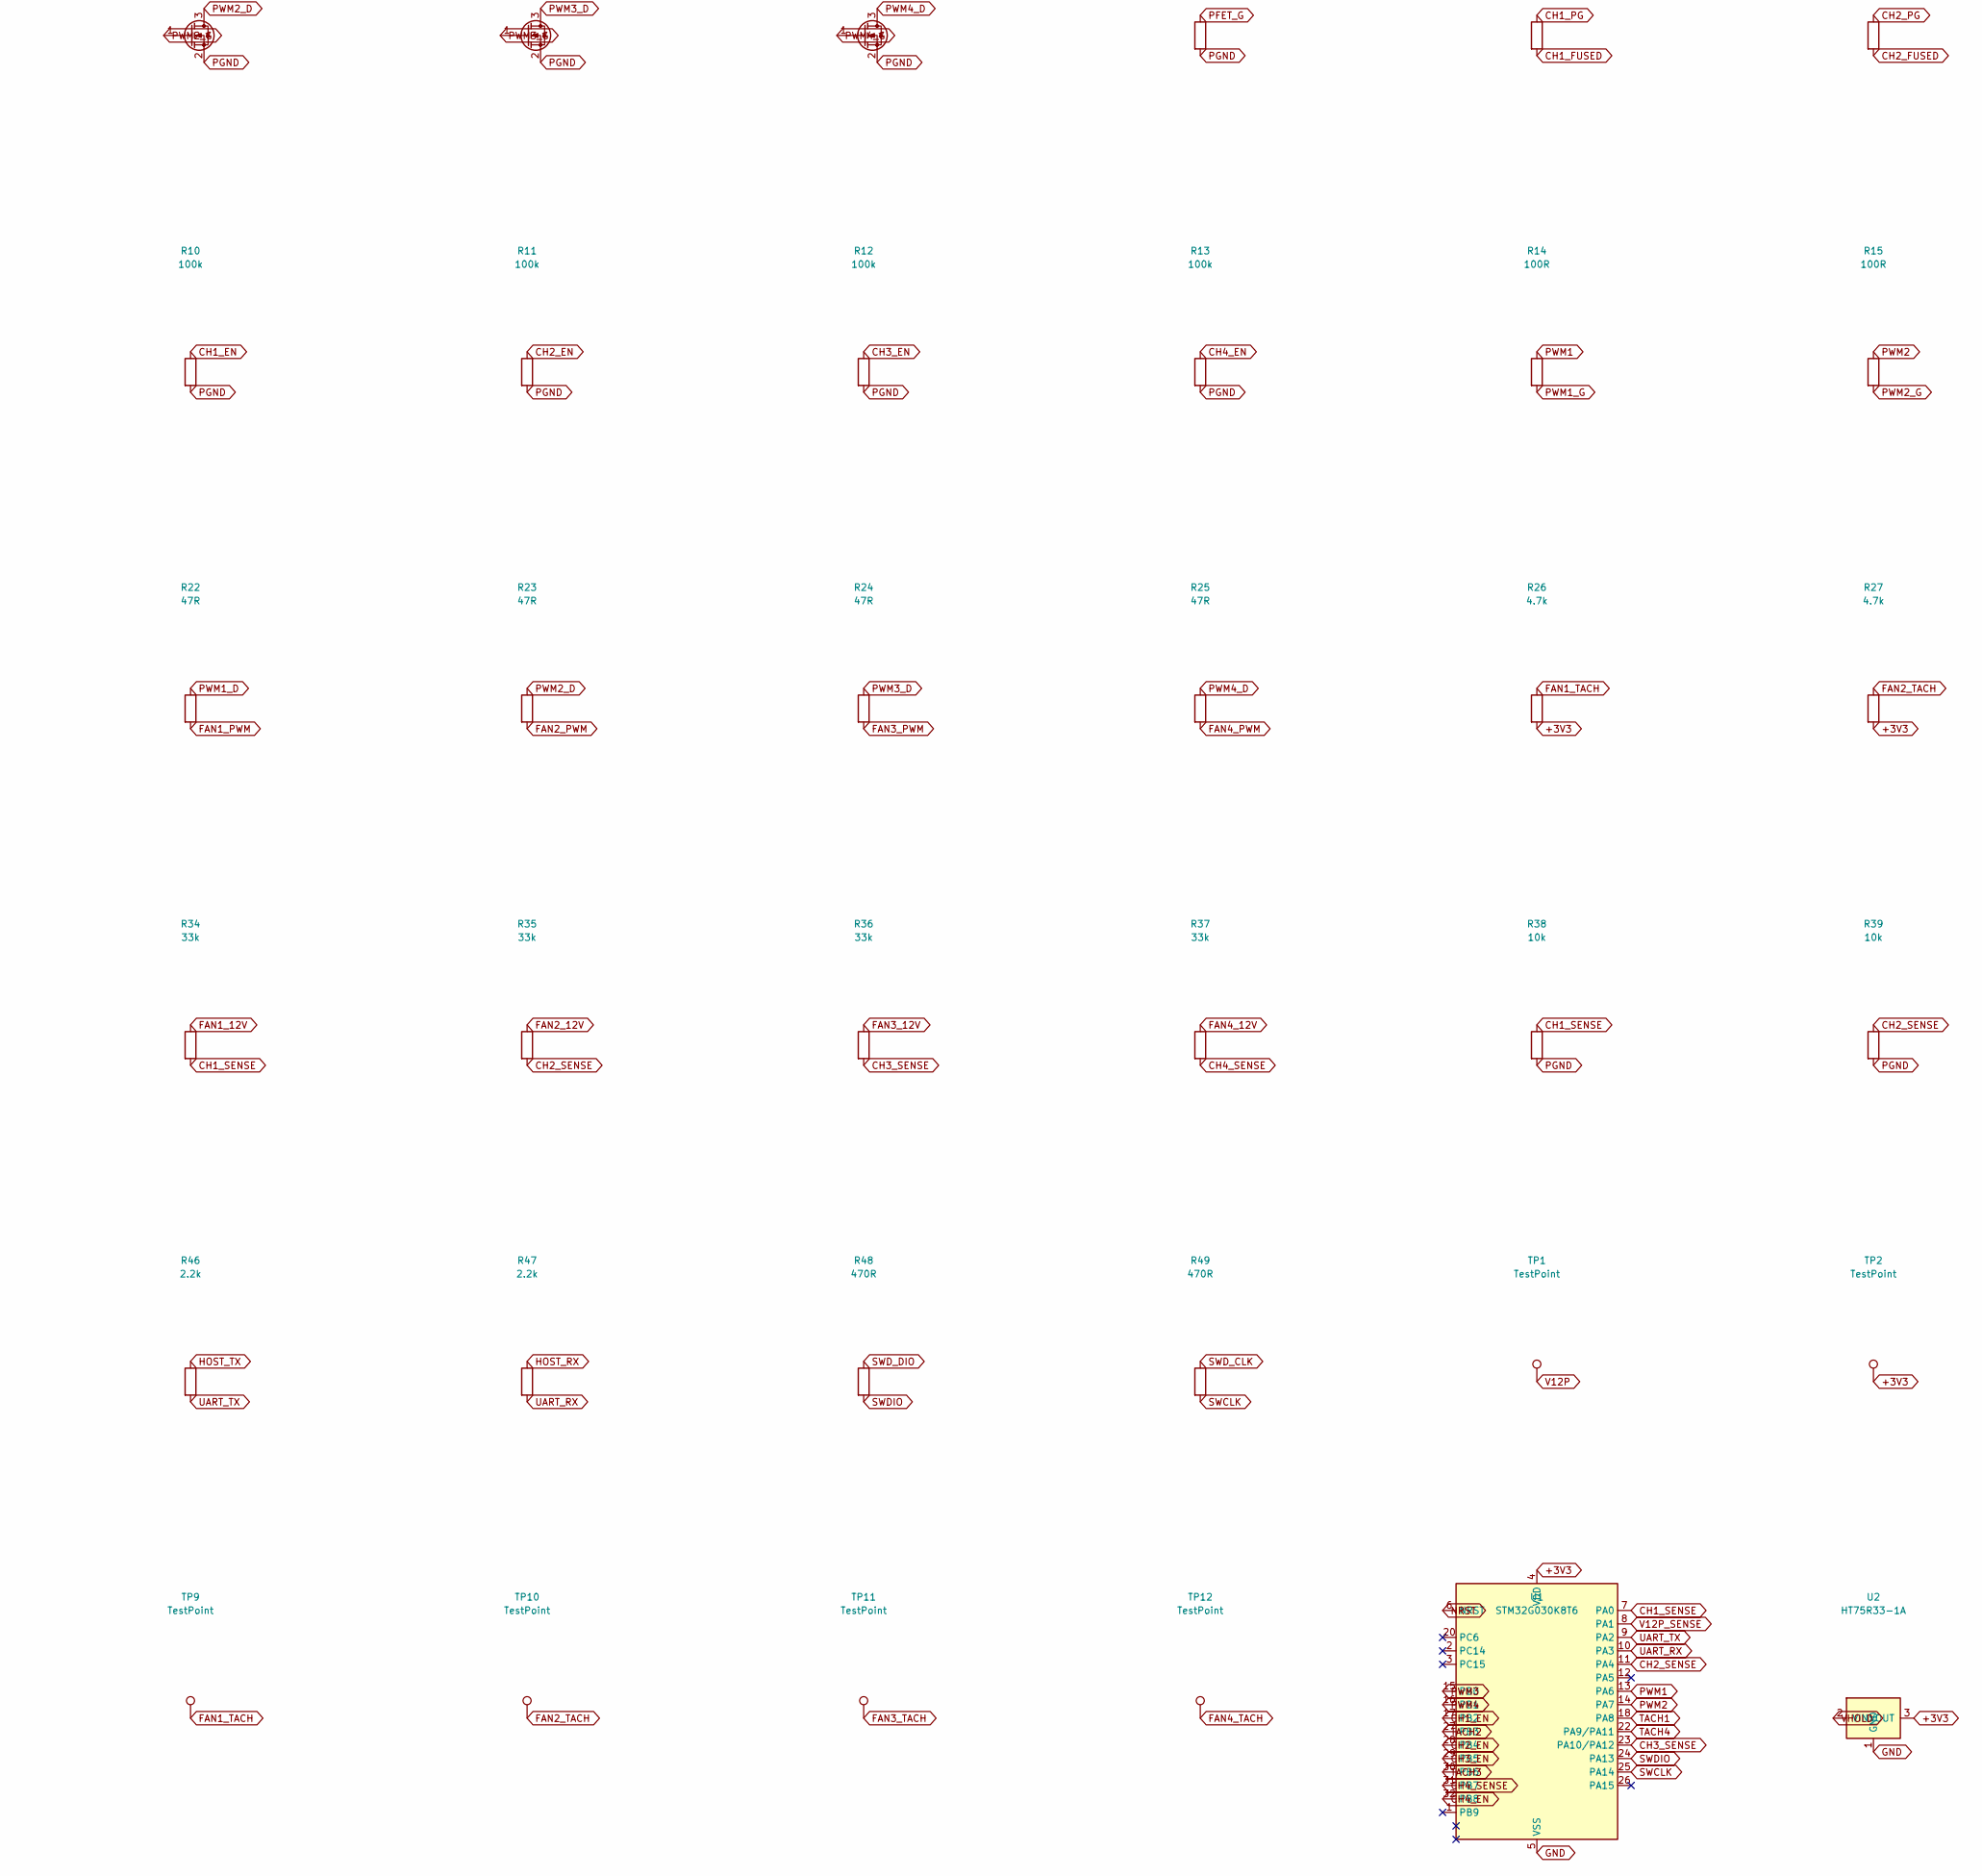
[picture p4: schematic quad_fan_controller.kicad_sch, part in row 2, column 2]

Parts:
C1, C3: 100uF; CP_Elec_6.3x7.7; MPN RVT100UF25V67RV0011; LCSC C2836443
C2, C4, C6, C7, C8: 100nF; C_0603_1608Metric; MPN CC0603KRX7R9BB104; LCSC C14663
C5: 10uF; C_0805_2012Metric; MPN CL21A106KAYNNNE; LCSC C15850
C9, C10, C11, C12: 1nF; C_0603_1608Metric; MPN CC0603KRX7R9BB102; LCSC C100040
D1: SMAJ16A; D_SMA; MPN SMAJ16A; LCSC C74561
D2, D3, D4, D5, D6, D7, D8, D9, D10: B5819W; D_SOD-123; MPN B5819W SL; LCSC C8598
D11, D12, D13, D14, D15, D16, D17, D18: SMF16A; D_SOD-123FL_1.2x1.2mm_P3.2mm; MPN SMF16A; LCSC C353308
D19, D20, D21, D22, D23: TPD1E10B06DPYR; TI_X1SON-2_1.0x0.6mm_P0.65mm; MPN TPD1E10B06DPYR; LCSC C48260
D24: KT-0603R; LED_0603_1608Metric; MPN KT-0603R; LCSC C2286
F1, F2, F3, F4: JK-MSMD200-24V; PTC_1812_Jinrui_JK-mSMD; MPN JK-MSMD200-24V; LCSC C561584
H1, H2, H3, H4: MountingHole_M3; MountingHole_3.2mm_M3
J1: KF128-5.08-2P-AA; TerminalBlock_KF128-5.08_1x02_P5.08mm; MPN KF128-5.08-2P-AA; LCSC C474952
J2, J3, J4, J5: KF2510-4AGW-GW; FanHeader_2510_1x04_P2.54mm_Horizontal; MPN KF2510-4AGW-GW; LCSC C722747
J6: KH-2.54PH180-1X3P-L11.5; PinHeader_1x03_P2.54mm_Vertical; MPN KH-2.54PH180-1X3P-L11.5; LCSC C2932698
J7: KH-2.54PH180-1X5P-L11.5; PinHeader_1x05_P2.54mm_Vertical; MPN KH-2.54PH180-1X5P-L11.5; LCSC C2932699
Q1: AO4407A; SOIC-8_3.9x4.9mm_P1.27mm; MPN AO4407A; LCSC C16072
Q2, Q3, Q4, Q5: AO3401A; SOT-23; MPN AO3401A; LCSC C15127
Q6, Q7, Q8, Q9, Q10, Q11, Q12, Q13: AO3400A; SOT-23; MPN AO3400A; LCSC C20917
R1, R2, R3, R4, R5, R6, R7, R8, R9, R10, R11, R12, R13, R18, R19, R20, R21: 100k; R_0603_1608Metric; MPN 0603WAF1003T5E; LCSC C25803
R14, R15, R16, R17: 100R; R_0603_1608Metric; MPN 0603WAF1000T5E; LCSC C22775
R22, R23, R24, R25: 47R; R_0603_1608Metric; MPN 0603WAF470JT5E; LCSC C23182
R26, R27, R28, R29, R30, R31, R32, R33: 4.7k; R_0603_1608Metric; MPN 0603WAF4701T5E; LCSC C23162
R34, R35, R36, R37, R42: 33k; R_0603_1608Metric; MPN 0603WAF3302T5E; LCSC C4216
R38, R39, R40, R41, R43: 10k; R_0603_1608Metric; MPN 0603WAF1002T5E; LCSC C25804
R44: 1.5k; R_0603_1608Metric; MPN 0603WAF1501T5E; LCSC C22843
R45: 0R; R_0603_1608Metric; MPN 0603WAF0000T5E; LCSC C21189
R46, R47: 2.2k; R_0603_1608Metric; MPN 0603WAF2201T5E; LCSC C4190
R48, R49: 470R; R_0603_1608Metric; MPN 0603WAF4700T5E; LCSC C23179
TP1, TP2, TP3, TP4, TP5, TP6, TP7, TP8, TP9, TP10, TP11, TP12: TestPoint; TestPoint_Pad_D1.0mm
U1: STM32G030K8T6; LQFP-32_7x7mm_P0.8mm; MPN STM32G030K8T6TR; LCSC C724044
U2: HT75R33-1A; SOT-89-3; MPN HT75R33-1A; LCSC C53223865

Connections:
+3V3: C5.1, C6.1, C7.1, D7.1 (K), D8.1 (K), D9.1 (K), D10.1 (K), J7.2, R26.2, R27.2, R28.2, R29.2, R44.1, TP2.1, U1.4 (VDD), U2.3 (VOUT)
CH1_EN: Q6.1 (G), R10.1, U1.17 (PB2)
CH1_FUSED: F1.2, Q2.2 (S), R2.2
CH1_GD: Q6.3 (D), R6.2
CH1_PG: Q2.1 (G), R2.1, R6.1
CH1_SENSE: R34.2, R38.1, U1.7 (PA0)
CH2_EN: Q7.1 (G), R11.1, U1.28 (PB4)
CH2_FUSED: F2.2, Q3.2 (S), R3.2
CH2_GD: Q7.3 (D), R7.2
CH2_PG: Q3.1 (G), R3.1, R7.1
CH2_SENSE: R35.2, R39.1, U1.11 (PA4)
CH3_EN: Q8.1 (G), R12.1, U1.29 (PB5)
CH3_FUSED: F3.2, Q4.2 (S), R4.2
CH3_GD: Q8.3 (D), R8.2
CH3_PG: Q4.1 (G), R4.1, R8.1
CH3_SENSE: R36.2, R40.1, U1.23 (PA10/PA12)
CH4_EN: Q9.1 (G), R13.1, U1.32 (PB8)
CH4_FUSED: F4.2, Q5.2 (S), R5.2
CH4_GD: Q9.3 (D), R9.2
CH4_PG: Q5.1 (G), R5.1, R9.1
CH4_SENSE: R37.2, R41.1, U1.31 (PB7)
FAN1_12V: D2.1 (K), J2.2 (+12V), Q2.3 (D), R34.1
FAN1_PWM: D11.1 (A1), J2.4 (CONTROL), R22.2, TP5.1
FAN1_TACH: D15.1 (A1), J2.3 (SENSE), R26.1, R30.1, TP9.1
FAN2_12V: D3.1 (K), J3.2 (+12V), Q3.3 (D), R35.1
FAN2_PWM: D12.1 (A1), J3.4 (CONTROL), R23.2, TP6.1
FAN2_TACH: D16.1 (A1), J3.3 (SENSE), R27.1, R31.1, TP10.1
FAN3_12V: D4.1 (K), J4.2 (+12V), Q4.3 (D), R36.1
FAN3_PWM: D13.1 (A1), J4.4 (CONTROL), R24.2, TP7.1
FAN3_TACH: D17.1 (A1), J4.3 (SENSE), R28.1, R32.1, TP11.1
FAN4_12V: D5.1 (K), J5.2 (+12V), Q5.3 (D), R37.1
FAN4_PWM: D14.1 (A1), J5.4 (CONTROL), R25.2, TP8.1
FAN4_TACH: D18.1 (A1), J5.3 (SENSE), R29.1, R33.1, TP12.1
GND: C3.2, C4.2, C5.2, C6.2, C7.2, C8.2, C9.2, C10.2, C11.2, C12.2, D19.1 (A1), D20.1 (A1), D21.1 (A1), D22.1 (A1), D23.1 (A1), D24.1 (K), J6.1, J7.1, R43.2, R45.1, TP3.1, U1.5 (VSS), U2.1 (GND)
HOST_RX: D20.2 (A2), J6.3, R47.1
HOST_TX: D19.2 (A2), J6.2, R46.1
NRST: C8.1, D23.2 (A2), J7.5, U1.6 (NRST)
PFET_G: Q1.4 (G), R1.1
PGND: C1.2, C2.2, D1.2 (A2), D2.2 (A), D3.2 (A), D4.2 (A), D5.2 (A), D11.2 (A2), D12.2 (A2), D13.2 (A2), D14.2 (A2), D15.2 (A2), D16.2 (A2), D17.2 (A2), D18.2 (A2), J1.2, J2.1 (GND), J3.1 (GND), J4.1 (GND), J5.1 (GND), Q6.2 (S), Q7.2 (S), Q8.2 (S), Q9.2 (S), Q10.2 (S), Q11.2 (S), Q12.2 (S), Q13.2 (S), R1.2, R10.2, R11.2, R12.2, R13.2, R18.2, R19.2, R20.2, R21.2, R38.2, R39.2, R40.2, R41.2, R45.2, TP4.1
PWM1: R14.1, U1.13 (PA6)
PWM1_D: Q10.3 (D), R22.1
PWM1_G: Q10.1 (G), R14.2, R18.1
PWM2: R15.1, U1.14 (PA7)
PWM2_D: Q11.3 (D), R23.1
PWM2_G: Q11.1 (G), R15.2, R19.1
PWM3: R16.1, U1.15 (PB0)
PWM3_D: Q12.3 (D), R24.1
PWM3_G: Q12.1 (G), R16.2, R20.1
PWM4: R17.1, U1.16 (PB1)
PWM4_D: Q13.3 (D), R25.1
PWM4_G: Q13.1 (G), R17.2, R21.1
PWR_LED_A: D24.2 (A), R44.2
SWCLK: R49.2, U1.25 (PA14)
SWDIO: R48.2, U1.24 (PA13)
SWD_CLK: D22.2 (A2), J7.4, R49.1
SWD_DIO: D21.2 (A2), J7.3, R48.1
TACH1: C9.1, D7.2 (A), R30.2, U1.18 (PA8)
TACH2: C10.1, D8.2 (A), R31.2, U1.27 (PB3)
TACH3: C11.1, D9.2 (A), R32.2, U1.30 (PB6)
TACH4: C12.1, D10.2 (A), R33.2, U1.22 (PA9/PA11)
UART_RX: R47.2, U1.10 (PA3)
UART_TX: R46.2, U1.9 (PA2)
V12IN: J1.1, Q1.5 (D), Q1.6 (D), Q1.7 (D), Q1.8 (D)
V12P: C1.1, C2.1, D1.1 (A1), D6.2 (A), F1.1, F2.1, F3.1, F4.1, Q1.1 (S), Q1.2 (S), Q1.3 (S), R42.1, TP1.1
V12P_SENSE: R42.2, R43.1, U1.8 (PA1)
VHOLD: C3.1, C4.1, D6.1 (K), U2.2 (VIN)

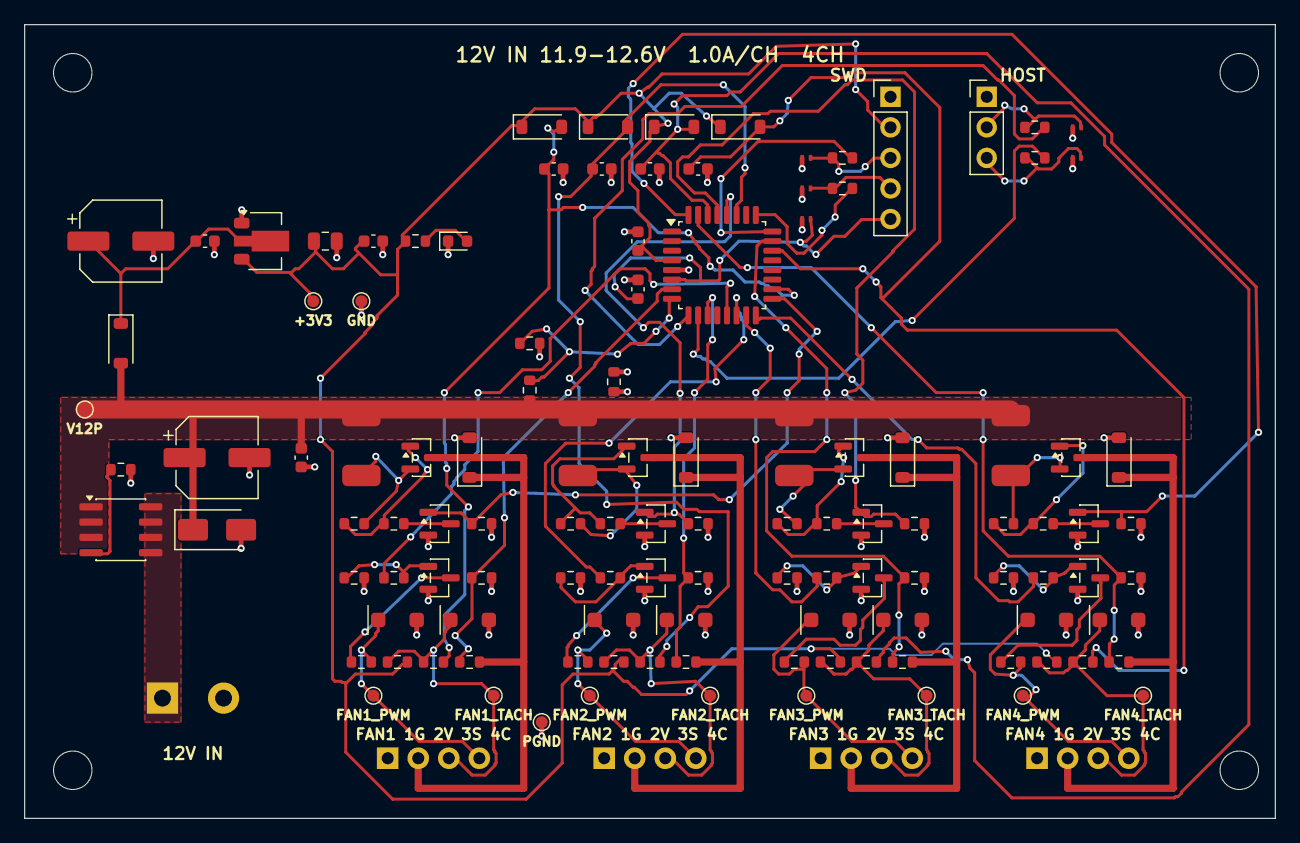
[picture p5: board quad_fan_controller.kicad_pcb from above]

Board: 2 copper layers, 104.0 x 66.0 mm, 127 parts (0 on the bottom side), 66 nets.

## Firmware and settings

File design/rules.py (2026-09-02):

"""Board-level electrical checks, stated as claims with their evidence.

Every number here comes from `components/parameters.json` (which cites the
frozen document it was read from), from the 4-wire fan specification, or from
the netlist. Nothing is asserted that a document, a component value or a
measurement does not support, and a quantity that cannot be established is
reported as UNKNOWN rather than assumed.
"""
from __future__ import annotations

import json
import os
import sys

from . import libraries, netlist

REPO_ROOT = os.path.dirname(os.path.dirname(os.path.abspath(__file__)))
PARAMETERS_PATH = os.path.join(REPO_ROOT, "components", "parameters.json")
CATALOG_PATH = os.path.join(REPO_ROOT, "components", "jlcpcb.json")
TOOLKIT_ROOT = os.path.join(REPO_ROOT, "tooling", "PCBA_AutoDesignAndTest")
FOOTPRINT_ROOT = "/usr/share/kicad/footprints"
LOCAL_FOOTPRINT_ROOT = os.path.join(REPO_ROOT, "library")

if TOOLKIT_ROOT not in sys.path:
    sys.path.insert(0, TOOLKIT_ROOT)

from pcbqa import claim  # noqa: E402

DIRECT = "direct"
ASSUMED = "assumed"
DERIVED = "derived"

EVIDENCE_CLASSES = {
    DIRECT: "datasheet-behavioral",
    ASSUMED: "assumed-behavioral",
    DERIVED: "design-source",
}

BRIEF = "BRIEF.md"
FAN_SPEC = "fan_4wire_intel"


def load_parameters():
    with open(PARAMETERS_PATH, "r", encoding="utf-8") as handle:
        return json.load(handle)


def load_catalog():
    with open(CATALOG_PATH, "r", encoding="utf-8") as handle:
        return json.load(handle)


def _mpn(reference):
    return netlist.PARTS[reference]["mpn"]


def _spec(parameters, reference):
    return parameters["parts"][_mpn(reference)]


def _evidence(basis, documents, assumptions=(), omissions=()):
    provenance = {"source": "components/parameters.json",
                  "documents": sorted(set(documents))}
    return claim.evidence(
        "device_electrical", EVIDENCE_CLASSES.get(basis, "design-source"),
        provenance, assumptions=list(assumptions),
        omitted_contributions=list(omissions))


def _requirement(name, op, value, source=BRIEF):
    return claim.requirement(name, source, {"op": op, "value": value})


#: How the requirement's operator turns a conservatively computed number into
#: the knowledge shape it actually supports. A worst case evaluated against a
#: floor is a lower bound on the real quantity; against a ceiling it is an
#: upper bound. Nothing that omits a contribution or rests on a premise is
#: ever allowed to call itself exact.
_BOUND_FOR_OPERATOR = {">=": claim.LOWER_BOUND, ">": claim.LOWER_BOUND,
                       "<=": claim.UPPER_BOUND, "<": claim.UPPER_BOUND}


def _claim(identity, units, significance, value, basis, documents,
           requirement, knowledge=None, scope_level="net",
           assumptions=(), omissions=()):
    if value is None:
        return claim.claim(
            scope_level, identity, units, claim.UNKNOWN, {},
            _evidence(basis, documents, assumptions, omissions),
            significance, None, requirement)
    if knowledge is None:
        if basis == ASSUMED or omissions:
            knowledge = _BOUND_FOR_OPERATOR.get(
                requirement["assertion"]["op"], claim.APPROXIMATE)
        else:
            knowledge = claim.EXACT
    basis_record = None
    if knowledge != claim.EXACT:
        basis_record = claim.knowledge_basis(
            basis, "datasheet_limit" if basis == DIRECT else basis)
    return claim.claim(
        scope_level, identity, units, knowledge, {"value": value},
        _evidence(basis, documents, assumptions, omissions),
        significance, basis_record, requirement)


def _structural(identity, significance, violations, requirement_name,
                documents=(), basis=DERIVED, assumptions=(), omissions=()):
    """A count of violations: zero is the only acceptable answer."""
    return _claim(identity, "violations", significance, float(len(violations)),
                  basis, documents, _requirement(requirement_name, "<=", 0.0),
                  scope_level="board", assumptions=assumptions,
                  omissions=omissions)


def _resistor_ohms(reference):
    value = netlist.PARTS[reference]["value"]
    if value.endswith("k"):
        return float(value[:-1]) * 1e3
    if value.endswith("R"):
        return float(value[:-1])
    raise ValueError("resistor %s carries the unparsable value %r"
                     % (reference, value))


def _capacitance_farads(reference):
    value = netlist.PARTS[reference]["value"]
    if value.endswith("uF"):
        return float(value[:-2]) * 1e-6
    if value.endswith("nF"):
        return float(value[:-2]) * 1e-9
    raise ValueError("capacitor %s carries the unparsable value %r"
                     % (reference, value))


def _resistor_tolerance(parameters, reference):
    spec = _spec(parameters, reference)["resistor"]
    entry = spec.get("tolerance")
    return 0.0 if entry is None else entry["value"]


def _channel_reference(prefix, channel, offset=0):
    return "%s%d" % (prefix, channel + offset)


# ---------------------------------------------------------------------------
# the supply model every rail and fan claim is built on

class Supply:
    """Worst-case rail voltages and currents, from parameters and values.

    Currents are upper bounds and drops are computed at the highest current
    and the highest resistance the datasheet and the tolerance permit, so no
    downstream figure is optimistic. The input range is the one declared at
    the board's terminal: the field wiring is the integrator's budget and
    appears only where a fault current is being bounded.
    """

    def __init__(self, parameters):
        self.parameters = parameters
        self.documents = {"stm32g030_st", "ht75rxx_holtek", "ao4407a_aos",
                          "ao3401a_aos", "pptc_jk_msmd200_jinrui",
                          "b5819w_jscj", "res_0603_uniroyal"}

        mcu = _spec(parameters, "U1")
        ldo = _spec(parameters, "U2")["regulator"]
        blocking = _spec(parameters, "Q1")["fet"]
        switch = _spec(parameters, "Q2")["fet"]
        fuse = _spec(parameters, "F1")["resettable_fuse"]
        holdup_diode = _spec(parameters, "D6")["diode"]

        self.input_min_v = netlist.INPUT_SUPPLY["min_v"]
        self.input_max_v = netlist.INPUT_SUPPLY["max_v"]
        self.channel_current_a = netlist.CHANNEL_CURRENT_RATING_A

        self.logic_rail_v = ldo["output_voltage_v"]["value"]
        tolerance = ldo["output_tolerance"]["value"]
        self.logic_rail_min_v = self.logic_rail_v * (1.0 - tolerance)
        self.logic_rail_max_v = self.logic_rail_v * (1.0 + tolerance)

        # Logic-side load, bounded rather than typical: the regulator's own
        # quiescent draw, the MCU at its stated maximum, every sense pull-up
        # held low at once, and the indicator taken as the whole rail across
        # its series resistor so no forward-voltage figure is needed.
        pull_up_min_ohm = _resistor_ohms("R26") * (
            1.0 - _resistor_tolerance(parameters, "R26"))
        self.tach_pull_up_current_a = self.logic_rail_max_v / pull_up_min_ohm
        indicator_min_ohm = _resistor_ohms("R44") * (
            1.0 - _resistor_tolerance(parameters, "R44"))
        self.indicator_current_max_a = self.logic_rail_max_v / indicator_min_ohm
        self.mcu_current_max_a = mcu["supply_current_max_a"]["value"]
        self.ldo_quiescent_a = ldo and _spec(
            parameters, "U2")["supply_current_max_a"]["value"]
        self.logic_current_max_a = (
            self.mcu_current_max_a + self.ldo_quiescent_a
            + netlist.CHANNEL_COUNT * self.tach_pull_up_current_a
            + self.indicator_current_max_a)

        # The blocking device runs with the whole rail across its gate, so the
        # -10 V on-resistance applies over the entire declared input range.
        self.blocking_rds_ohm = blocking["rds_on_ohm"]["-10"]["value"]
        self.total_input_current_a = (
            netlist.CHANNEL_COUNT * self.channel_current_a
            + self.logic_current_max_a)
        self.blocking_drop_max_v = (self.total_input_current_a
                                    * self.blocking_rds_ohm)
        self.protected_min_v = self.input_min_v - self.blocking_drop_max_v
        self.protected_max_v = self.input_max_v

        # The channel switch is driven from a divider off the protected rail,
        # so its gate sits near half of it and the -4.5 V on-resistance is the
        # figure that applies, not the -10 V one.
        self.switch_gate_v = self.protected_min_v * _resistor_ohms("R2") / (
            _resistor_ohms("R2") + _resistor_ohms("R6"))
        self.switch_gate_max_v = self.protected_max_v * _resistor_ohms("R2") / (
            _resistor_ohms("R2") + _resistor_ohms("R6"))
        self.switch_rds_ohm = switch["rds_on_ohm"]["-4.5"]["value"]
        self.fuse_resistance_max_ohm = fuse["resistance_max_ohm"]["value"]
        self.fuse_resistance_min_ohm = fuse["resistance_min_ohm"]["value"]

        self.channel_drop_max_v = self.channel_current_a * (
            self.fuse_resistance_max_ohm + self.switch_rds_ohm
            + netlist.BOARD_COPPER_BUDGET_OHM)
        self.fan_supply_min_v = self.protected_min_v - self.channel_drop_max_v
        self.fan_supply_max_v = self.protected_max_v

        # The hold-up reservoir sits behind a diode, so a collapse of the fan
        # bus cannot pull it down. Its floor is what the regulator needs to
        # keep regulating.
        self.holdup_diode_drop_v = holdup_diode[
            "forward_voltage_max_v"]["1"]["value"]
        self.hold_up_min_v = self.protected_min_v - self.holdup_diode_drop_v
        self.regulator_floor_v = (self.logic_rail_max_v
                                  + ldo["dropout_bound_v"]["value"])
        self.hold_up_farads = _capacitance_farads(
            netlist.HOLD_UP_BULK_REFERENCES[0]) * (
            1.0 - _spec(parameters, netlist.HOLD_UP_BULK_REFERENCES[0])[
                "capacitor"]["tolerance"]["value"])


# ---------------------------------------------------------------------------
# fan supply

def evaluate_fan_supply(parameters):
    """Every fan sees a supply inside the window its standard requires."""
    supply = Supply(parameters)
    documents = ("ao4407a_aos", "ao3401a_aos", "pptc_jk_msmd200_jinrui")
    results = []
    for channel in range(1, netlist.CHANNEL_COUNT + 1):
        net = "FAN%d_12V" % channel
        results.append({
            "id": "fan_supply_above_standard_minimum",
            "identity": net,
            "measured_v": supply.fan_supply_min_v,
            "claim": _claim(
                net, "V", "interface_compliance", supply.fan_supply_min_v,
                DIRECT, documents,
                _requirement("above_fan_standard_minimum", ">=",
                             netlist.FAN_SUPPLY["min_v"], FAN_SPEC),
                assumptions=(
                    "every channel carries its full rated current at once, "
                    "which is the worst case for the shared blocking device",
                    "board copper between the terminal and a fan connector is "
                    "the declared budget, not a measurement",),
                omissions=(
                    "the fan cable's own resistance is outside the board and "
                    "is not included",)),
        })
        results.append({
            "id": "fan_supply_below_standard_maximum",
            "identity": net,
            "measured_v": supply.fan_supply_max_v,
            "claim": _claim(
                net, "V", "interface_compliance", supply.fan_supply_max_v,
                DERIVED, documents,
                _requirement("below_fan_standard_maximum", "<=",
                             netlist.FAN_SUPPLY["max_v"], FAN_SPEC),
                assumptions=(
                    "the board has no series element that raises a voltage, "
                    "so the highest a fan pin can reach is the highest the "
                    "input terminal is declared for",)),
        })
    return results


# ---------------------------------------------------------------------------
# per-channel protection

def evaluate_channel_protection(parameters):
    supply = Supply(parameters)
    fuse = _spec(parameters, "F1")["resettable_fuse"]
    hold = fuse["hold_current_a"]
    ambient = "%d" % int(netlist.AMBIENT_MAX_C)
    if ambient not in hold:
        raise KeyError("no hold current is tabulated at %s C" % ambient)
    hold_current_a = hold[ambient]["value"]
    results = []
    for channel in range(1, netlist.CHANNEL_COUNT + 1):
        reference = "F%d" % channel
        results.append({
            "id": "channel_fuse_holds_the_rated_current",
            "identity": reference,
            "measured_a": hold_current_a,
            "claim": _claim(
                reference, "A", "protection", hold_current_a, DIRECT,
                ("pptc_jk_msmd200_jinrui",),
                _requirement("holds_the_channel_rating", ">=",
                             netlist.CHANNEL_CURRENT_RATING_A),
                scope_level="group",
                assumptions=(
                    "the fuse is at the board's declared maximum ambient of "
                    "%g C, read from the datasheet's derating table rather "
                    "than interpolated" % netlist.AMBIENT_MAX_C,),
                omissions=(
                    "self-heating of neighbouring parts is not included; the "
                    "datasheet asks that no heat source sit beside the fuse "
                    "and that is a placement constraint, not a number here",)),
        })
        results.append({
            "id": "channel_fuse_passes_the_standard_start_up_surge",
            "identity": reference,
            "measured_a": netlist.FAN_SPEC_STARTUP_CURRENT_MAX_A,
            "claim": _claim(
                reference, "A", "protection",
                netlist.FAN_SPEC_STARTUP_CURRENT_MAX_A, DIRECT,
                ("pptc_jk_msmd200_jinrui",),
                _requirement("below_the_always_trip_current", "<=",
                             fuse["trip_current_a"]["value"], FAN_SPEC),
                scope_level="group",
                assumptions=(
                    "below the always-trip current the device may or may not "
                    "trip; the standard permits the surge for one second and "
                    "the datasheet's guaranteed trip time at twice this "
                    "current is longer than that",),
                omissions=(
                    "the time-current curve is typical, so the surge is shown "
                    "to be below the always-trip current rather than shown "
                    "not to trip",)),
        })
    # A bolted short downstream of one fuse, limited by the declared field
    # wiring and by the least resistance the path can have.
    fault_path_ohm = (netlist.INPUT_PATH_BUDGET_OHM
                      + supply.blocking_rds_ohm
                      + supply.fuse_resistance_min_ohm
                      + supply.switch_rds_ohm
                      + netlist.BOARD_COPPER_BUDGET_OHM)
    fault_current_a = supply.input_max_v / fault_path_ohm
    results.append({
        "id": "channel_short_current_within_the_fuse_rating",
        "identity": "F1",
        "measured_a": fault_current_a,
        "claim": _claim(
            "F1", "A", "protection", fault_current_a, DIRECT,
            ("pptc_jk_msmd200_jinrui", "ao4407a_aos", "ao3401a_aos"),
            _requirement("within_the_fuse_maximum_fault_current", "<=",
                         _spec(parameters, "F1")["resettable_fuse"][
                             "fault_current_max_a"]["value"]),
            scope_level="group",
            assumptions=(
                "the supply and its wiring present the declared %g ohm; a "
                "stiffer source raises the fault current"
                % netlist.INPUT_PATH_BUDGET_OHM,
                "the fuse is at its minimum resistance, which is the worst "
                "case for fault current",)),
    })
    return results


# ---------------------------------------------------------------------------
# the channel switch

def evaluate_channel_switch(parameters):
    supply = Supply(parameters)
    switch = _spec(parameters, "Q2")["fet"]
    driver = _spec(parameters, "Q6")["fet"]
    mcu = _spec(parameters, "U1")
    characterised_v = min(abs(float(key))
                          for key in switch["rds_on_ohm"])
    results = []
    for channel in range(1, netlist.CHANNEL_COUNT + 1):
        net = "CH%d_PG" % channel
        results.append({
            "id": "channel_switch_fully_on_at_its_gate_drive",
            "identity": net,
            "measured_v": supply.switch_gate_v,
            "claim": _claim(
                net, "V", "gate_drive", supply.switch_gate_v, DIRECT,
                ("ao3401a_aos", "res_0603_uniroyal"),
                _requirement("at_or_above_a_characterised_drive", ">=",
                             characterised_v),
                assumptions=(
                    "the gate divider is at its nominal ratio; both resistors "
                    "are the same value and the same tolerance, so tolerance "
                    "moves the ratio far less than it moves either value",)),
        })
        results.append({
            "id": "channel_switch_gate_within_its_rating",
            "identity": net,
            "measured_v": supply.switch_gate_max_v,
            "claim": _claim(
                net, "V", "absolute_maximum", supply.switch_gate_max_v, DIRECT,
                ("ao3401a_aos",),
                _requirement("within_the_gate_source_rating", "<=",
                             switch["vgs_max_v"]["value"])),
        })
        # With the enable pin floating, the driver's own drain leakage is the
        # only current in the gate divider, so the switch sees almost nothing.
        leakage_a = driver["drain_leakage_max_a"]["value"]
        residual_v = abs(leakage_a) * _resistor_ohms("R6")
        results.append({
            "id": "channel_off_when_the_enable_pin_does_not_drive",
            "identity": net,
            "measured_v": residual_v,
            "claim": _claim(
                net, "V", "safe_state", residual_v, DIRECT,
                ("ao3400a_aos", "ao3401a_aos"),
                _requirement("below_the_switch_threshold", "<=",
                             abs(switch["vgs_threshold_min_v"]["value"])),
                assumptions=(
                    "the worst case is the enable device at its maximum "
                    "drain leakage, which is stronger than the pull-down the "
                    "MCU pin sees while it is an input",)),
        })
        enable_net = "CH%d_EN" % channel
        pull_down_v = (mcu["input_leakage_max_a"]["value"]
                       * _resistor_ohms("R10"))
        results.append({
            "id": "enable_pin_defined_before_firmware_drives_it",
            "identity": enable_net,
            "measured_v": pull_down_v,
            "claim": _claim(
                enable_net, "V", "safe_state", pull_down_v, DIRECT,
                ("stm32g030_st", "ao3400a_aos"),
                _requirement("below_the_enable_device_threshold", "<=",
                             driver["vgs_threshold_min_v"]["value"])),
        })
    return results


# ---------------------------------------------------------------------------
# the control output
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

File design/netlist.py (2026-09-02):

from __future__ import annotations

import os

CHANNEL_COUNT = 4

PROJECT_NAME = "quad_fan_controller"

_REPO_ROOT = os.path.dirname(os.path.dirname(os.path.abspath(__file__)))

SYMBOL_LIBRARY_PATHS = (
    os.path.join(_REPO_ROOT, "library"),
    "/usr/share/kicad/symbols",
)

LIBRARY_NAME = "QuadFanController"

#: Fan connector function -> connector pin, from the 4-wire fan specification
#: table 1. The order is the whole point of the connector: a plug that mates
#: mechanically but not in this order destroys the fan.
FAN_CONNECTOR_PINS = {"GND": 1, "12V": 2, "SENSE": 3, "CONTROL": 4}

#: MCU pin each channel signal lands on, in channel order. LQFP-32 pin numbers
#: from DS12991 figure 4; the peripheral each one carries is in
#: CHANNEL_PWM_FUNCTIONS / CHANNEL_TACH_FUNCTIONS below.
CHANNEL_PWM_PINS = ("13", "14", "15", "16")
CHANNEL_TACH_PINS = ("18", "27", "30", "22")
CHANNEL_ENABLE_PINS = ("17", "28", "29", "32")
CHANNEL_SENSE_PINS = ("7", "11", "23", "31")

#: The four PWM outputs are four compare channels of one timer, and the four
#: tach inputs are four capture channels of another, so each group shares a
#: counter, a prescaler and a period: equal frequency and equal resolution on
#: every channel is a property of the pin choice, not of the firmware.
CHANNEL_PWM_FUNCTIONS = ("TIM3_CH1", "TIM3_CH2", "TIM3_CH3", "TIM3_CH4")
CHANNEL_TACH_FUNCTIONS = ("TIM1_CH1", "TIM1_CH2", "TIM1_CH3", "TIM1_CH4")

#: ADC channel behind each sense divider, and behind the input-rail divider.
CHANNEL_SENSE_FUNCTIONS = ("ADC_IN0", "ADC_IN4", "ADC_IN16", "ADC_IN11")
RAIL_SENSE_FUNCTION = "ADC_IN1"
RAIL_SENSE_PIN = "8"

#: Pins the datasheet's injection-susceptibility table says tolerate no
#: negative injection at all. A conductor that leaves the board may be driven
#: below the reference, so no such conductor reaches one of these.
MCU_NO_NEGATIVE_INJECTION_PINS = {
    "8": "PA1", "12": "PA5", "24": "PA13", "16": "PB1", "17": "PB2",
    "32": "PB8",
}

#: Pins the LQFP-32 brings out that this board does not use. Pins 19 and 21
#: are the two the datasheet pinout calls PA9 and PA10 and the KiCad symbol
#: calls NC: the contradiction is unresolved, so the design does not depend on
#: either reading.
MCU_UNUSED_PINS = ("1", "2", "3", "12", "19", "20", "21", "26")

#: The two package pins whose identity the sources disagree about, and what
#: each source says. Recorded so the disagreement is visible rather than
#: silently resolved in favour of whichever was read last.
MCU_CONTESTED_PINS = {
    "19": {"datasheet": "PA9", "symbol": "NC/PA9"},
    "21": {"datasheet": "PA10", "symbol": "NC/PA10"},
}


def _part(lib_id, footprint, value, mpn=None, manufacturer=None, lcsc=None,
          datasheet="", in_bom=True, on_board=True):
    return {
        "lib_id": lib_id,
        "footprint": footprint,
        "value": value,
        "mpn": mpn,
        "manufacturer": manufacturer,
        "lcsc": lcsc,
        "datasheet": datasheet,
        "in_bom": in_bom,
        "on_board": on_board,
    }


def _resistor(value, lcsc, mpn):
    return _part("Device:R", "Resistor_SMD:R_0603_1608Metric", value,
                 mpn, "UNI-ROYAL(Uniroyal Elec)", lcsc)


def _capacitor(value, footprint, lcsc, mpn, manufacturer,
               lib_id="Device:C"):
    return _part(lib_id, footprint, value, mpn, manufacturer, lcsc)


#: Resistor values used on this board, and the catalogue part behind each.
RESISTOR_PARTS = {
    "0R": ("C21189", "0603WAF0000T5E"),
    "47R": ("C23182", "0603WAF470JT5E"),
    "100R": ("C22775", "0603WAF1000T5E"),
    "1.5k": ("C22843", "0603WAF1501T5E"),
    "2.2k": ("C4190", "0603WAF2201T5E"),
    "4.7k": ("C23162", "0603WAF4701T5E"),
    "470R": ("C23179", "0603WAF4700T5E"),
    "10k": ("C25804", "0603WAF1002T5E"),
    "33k": ("C4216", "0603WAF3302T5E"),
    "100k": ("C25803", "0603WAF1003T5E"),
}

#: Where every resistor goes. The index is the reference number; channel
#: blocks are laid out as four consecutive numbers so the layout can group
#: them without a second table.
_RESISTOR_VALUES = {1: "100k", 42: "33k", 43: "10k", 44: "1.5k", 45: "0R",
                    46: "2.2k", 47: "2.2k", 48: "470R", 49: "470R"}
for _base, _value in ((2, "100k"), (6, "100k"), (10, "100k"), (14, "100R"),
                      (18, "100k"), (22, "47R"), (26, "4.7k"), (30, "4.7k"),
                      (34, "33k"), (38, "10k")):
    for _offset in range(CHANNEL_COUNT):
        _RESISTOR_VALUES[_base + _offset] = _value
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

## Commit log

2026-08-30 Seed benchmark board 04/32 from its supplied brief
    PCBA_4Fan_Controller is one of thirty-two boards in the PCBA_AutoDesignAndTest
    benchmark. This commit establishes the repository and nothing else:
    the board is not designed, and its absence is the intended state.
    BRIEF.md is the supplied brief, preserved byte for byte and
    authoritative. board/requirements.json splits it into fixed_requirements
    -- each carrying the verbatim brief text that substantiates it, bound to
    the SHA-256 of the brief's bytes -- and open_decisions, which are the
    design agent's to make and to record as choices. Promoting a decision
    into a requirement is the failure the split exists to prevent.
    docs/architecture.md is a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
2026-08-30 Stop the scaffold claiming a check it does not perform
    An external review of the pushed benchmark found this repository asserting
    three things about itself that were not true as shipped.
    board/manifest.template.json said running the validator against it "will
    fail on the missing source". It does not: `run.py validate
    board/manifest.template.json` exits 0 and prints ACCEPTED, with all 36 gates
    NOT_APPLICABLE and no gate reading sources.pcb, so the absent board file is
    never noticed. The template now says exactly that, under verdict_warning,
    and docs/status.md and CLAUDE.md carry the same warning where a reader and
    an agent will actually meet it. The toolkit is behaving as designed - a gate
    w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
2026-08-30 Remove the claim-audit skill, and the instructions that called it
    Requested. .claude/skills/claim-audit/ is deleted, and with it every
    reference: CLAUDE.md's publishing discipline no longer names it, and the
    README layout table no longer advertises it.
    accountability-review kept calling it at step 3, which would have left the
    surviving skill invoking one that is not in the clone - the same
    dangling-instruction defect that put these skills in the repository in the
    first place. That step now states the claim-binding work directly: scan the
    drafts for claim-bearing words, and bind each to an artifact recomputed on
    the spot rather than to the process that produced it. The discipline is
    unchange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
2026-08-30 Finish removing claim-audit: the last prose reference to it
    accountability-review still explained itself with "that is why the claim
    audit runs first". Nothing runs first any more - the claim binding is step 3
    of this skill, and it runs before the review package is assembled, not
    before the review. The sentence now says that.
    Removing a skill is not done when its file is gone. It is done when nothing
    left in the repository tells a reader to go and find it.
2026-08-30 Review against this repository's own invariants, not another board's
    /accountability-review assembled its review package with a hardcoded list
    of "standing invariants", and that list belonged to a different project and
    an abandoned workflow: "never modify the authoritative Board A PCB" names a
    board that does not exist here, and "never touch main" and "no PRs"
    describe a process the opposite of this one -- every repository in this
    benchmark is developed on main and pushed directly.
    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
2026-08-30 Delete generated prose; keep the seed brief and machine-consumed config
    The seed pack already contained the human-authored specification for this
    board. Everything this repository added on top was a reinterpretation of it:
    a README and CLAUDE.md narrating the brief, an architecture worksheet of
    English questions, status and sources documents, a prose requirements
    document, and requirements.json - which restated the brief as English
    requirement strings and copied 20-odd verbatim quotations back out of a file
    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
2026-09-02 Design the quad fan controller schematic and its evidence
    Four independent 12 V channels, each with a resettable fuse, a high-side
    switch the controller enables, an open-drain control driver, a sense
    pull-up and an output-voltage divider; a reverse-blocking input, a
    diode-isolated hold-up reservoir feeding the logic regulator, and one
    deliberate link between the fan return and the sense reference.
    The 4-wire fan specification is frozen alongside the component datasheets,
    so the interface requirements it defines - control band, low level, sink
    current, open-circuit level, pin order, permitted currents - are evaluated
    rather than asserted. 172 claims, one of which is UNKNOWN: whether the
    sele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
    [quad_fan_controller.kicad_sch]
2026-09-02 Simulate the four questions the schematic can answer
    Four ngspice scenarios, all converging and all asserting: the reservoir
    behind the hold-up diode while every channel takes the standard's maximum
    start-up current at once; the control output reaching a valid low inside
    its on-time against the cable and clamp capacitance and the strongest
    pull-up the standard permits a fan to present; the sense input resolving
    pulses at the top rotation rate the board claims, solved rather than
    bounded by hand; and both gates with nothing driving them.
    The safe-state scenario carries a third branch with no assertion. It
    measures what the control gate would reach if firmware enabled an internal
    pull-up at t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
    [rules.py]
2026-09-02 Advance the QuadFanController to a routed, fabricable board
    Place the four channels as identical lanes above a split ground, route
    them, and package the result. Every applicable gate passes: DRC, ERC,
    net topology, both connector and placement contracts, route provenance,
    geometry hygiene, tiny segments, the via and mask gates, stackup, gerber
    parity, BOM and CPL parity, report freshness and the four SPICE
    scenarios.
    Three things the router does had to be answered rather than absorbed.
    It carries its own fab-capability floor - 0.127 mm clearance on two
    layers - and escalates below the nominal clearance to fit tight
    geometry, recording the tighter value so the board is graded against
    it; thi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
    [bom.csv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]
2026-09-02 Rebuild the QuadFanController release against the settled sources
    The first package was cut before the requirement evaluation was
    regenerated, so its reports bound a source set that no longer existed.
    Repackage and record the validation report the release check asks for.
    [quad_fan_controller-B_Cu.gbr, quad_fan_controller-B_Mask.gbr, quad_fan_controller-B_Silkscreen.gbr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]
2026-09-03 Record what this board needed from the toolkit and did not have
2026-09-03 Rebind the release to the phase 0 toolkit
    The toolkit now validates every manifest against its published schema
    and refuses vocabulary it does not implement, so the board-local gate
    list moves under the x_ extension prefix; gate-class selection
    (--only=design) supersedes it. Regenerated and revalidated against
    toolkit f4d3904: 22 gates pass, 14 report NOT_APPLICABLE, and
    the fabrication record now carries the source-closure member map, so
    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
    [quad_fan_controller-B_Cu.gbr, quad_fan_controller-B_Mask.gbr, quad_fan_controller-B_Silkscreen.gbr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]
2026-09-03 Retire the hand-written routing acceptance list
    The toolkit's design gate class replaces it: candidate acceptance now
    selects --only=design, expanded by the toolkit, so the set cannot rot
    as gates are added. The list leaves the manifest and the generator that writes it, and the
    release is regenerated under toolkit b441685, which also closes the
    review findings on the phase 0 seams: 22 gates pass, 14 report
    NOT_APPLICABLE.
    [quad_fan_controller-B_Cu.gbr, quad_fan_controller-B_Mask.gbr, quad_fan_controller-B_Silkscreen.gbr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]
2026-09-03 Close the adversarial findings that reached this board
    The unread keys the manifest carried are gone: tolerance_seconds is
    deleted, contact_semantics becomes the note annotation it always was,
    and the schema now refuses both by name. The routing acceptance
    selection regains ROUTE.PROVENANCE - the loop writes the record before
    judging, so record-board agreement is judged per candidate as it was
    under the hand-written list. Regenerated and revalidated under
    toolkit a0f53eb: 22 gates pass, 14 report NOT_APPLICABLE.
    [quad_fan_controller-B_Cu.gbr, quad_fan_controller-B_Mask.gbr, quad_fan_controller-B_Silkscreen.gbr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]
2026-09-03 Rebind the release to toolkit 0c051f2
    The toolkit keeps its CLI alive with no display and closes the third
    review round's findings; nothing in this board's own sources moved.
    22 gates pass, 14 report NOT_APPLICABLE.
    [quad_fan_controller-B_Cu.gbr, quad_fan_controller-B_Mask.gbr, quad_fan_controller-B_Silkscreen.gbr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]
2026-09-03 Rebind the release to toolkit 7f51066
    The panel-fix round widened the source closure to every staged design
    input and hardened the verdict binding, so the fabrication outputs and
    the recorded verdict are regenerated under the new toolkit. The
    transient .pcbqa-hold-* lock file is ignored.
    [quad_fan_controller-B_Cu.gbr, quad_fan_controller-B_Mask.gbr, quad_fan_controller-B_Silkscreen.gbr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]
